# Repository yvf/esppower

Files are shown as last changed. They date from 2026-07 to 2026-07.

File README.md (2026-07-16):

# AC Power Detector & Linear Actuator Driver for HomeKit / Matter

A small battery-powered device that watches for mains AC power and, when the power
drops, extends a  with a linear actuator (meant to physically switch power back on)
and interfaces with Apple Home over Matter/Thread.

It's aimed at unattended installations where a *nuisance* trip would otherwise leave
something important without power until someone visits: an off-grid pump, a remote
freezer, a holiday home. The device notices the outage, attempts a reset, and if the
supply doesn't come back it stops and raises an alert.

## What it does

- **Senses mains power** contactlessly - a custom EMF sensor board picks up the field
  around a live conductor, so there's no direct mains connection to the electronics.
- **Auto-resets on power loss** - after a debounce, it drives the actuator through one or
  two reset cycles. If power returns, it stands down; if not, it latches and waits.
- **Manual reset from your phone** - tap the tile in Apple Home to fire a reset cycle.
- **Live status + trip alerts** - Home shows whether power is present and can notify you
  when it's lost.
- **Battery friendly** - contactless sensing (no mains tap), efficient bare-metal
  firmware, and a low-power Thread mesh radio make long battery operation practical.
- **12v supply** - requires a 12v supply (required for the actuator) and drives 5v from
  there.

## In Apple Home

The device appears as two tiles under one accessory:

- a **contact sensor** (the main tile) - power present / lost, with trip notifications;
- a **switch** - tap to trigger a manual reset (it returns to off on its own).

See [`docs/matter_device_choices.md`](docs/matter_device_choices.md) for why those Matter
device types were chosen.

## Hardware

- **Espressif ESP32-H2** - a RISC-V microcontroller with built-in 802.15.4 (Thread) and
  Bluetooth radios. Development uses the ESP32-H2 devkit.
- **Custom EMF sensor board** - a contactless mains-presence detector with an op-amp front
  end. Design files (schematic, PCB, BOM, gerbers) and write-up are in
  [`emf_sensor/`](emf_sensor/).
- **Actuonix L12 linear actuator** - the small motor that mechanically flips the breaker
  lever, driven as a standard RC servo.

## Software & stack

Bare-metal **`no_std` Rust** (no operating system), talking **Matter over Thread** so the
device joins an existing Apple Home / Thread network. The main building blocks:

- **esp-hal / esp-rtos** - chip support and async runtime
- **OpenThread** - the Thread (802.15.4) mesh networking
- **trouble** - Bluetooth, used only for initial pairing
- **rs-matter** - the Matter application layer

Running bare-metal (rather than on a full RTOS framework) is what makes the whole stack
fit in the ESP32-H2's limited memory - and keeps power draw low. The reasoning, the full
component list, and how to build/flash are in
[**`docs/no-std-plan.md`**](docs/no-std-plan.md).

## Build

```sh
./build.sh                 # build the firmware
./build.sh run --release   # flash to a connected ESP32-H2 and monitor
```

Host prerequisites are listed in [`docs/no-std-plan.md`](docs/no-std-plan.md).

## More documentation

- [`docs/no-std-plan.md`](docs/no-std-plan.md) - architecture, dependency stack, build setup
- [`docs/matter_device_choices.md`](docs/matter_device_choices.md) - the HomeKit / Matter device model
- [`docs/phase4b-glue-design.md`](docs/phase4b-glue-design.md) - the Matter transport layer design
- [`emf_sensor/`](emf_sensor/) - the custom power-sensor board and detection approach

## Status

Working end-to-end on hardware: it commissions over Bluetooth, operates over Thread,
drives the actuator, and reports power status to Home. It currently uses Matter's standard
**test** device credentials - fine with tools like chip-tool and Home Assistant; adding it
to **Apple Home** requires production Matter credentials (a certified vendor ID + device
certificate).

## Disclaimer

More seriously: the code is almost entirely written by Claude, with only high-level human review.
It works for me, compiled on my M2 MacBook, on my esp32-h2 version and other bits. No guarantee it
will for you.

Somewhat less seriously, but perhaps needs saying: this implements a device that affects the real
world. Exercise good judgement, and use at your own risk. Fiddling around with mains AC power and
RCDs is inherently risky. It works for my usecase, but YMMV. If you don't know what you're doing, and
this ends up launching your house all the way to the moon and you with it, don't blame me.

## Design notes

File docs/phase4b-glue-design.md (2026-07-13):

# Phase 4b - rs-matter-stack transport glue (design / roadmap)

> **Status (2026-07-05): fully implemented and working on hardware.** All five
> adapters exist under `src/matter/` (`net.rs`, `netif.rs`, `mdns.rs`, `netctl.rs`,
> `gatt.rs`) and the stack commissions + operates end-to-end. **Key deviation from
> the plan below:** the run loop uses **non-concurrent `stack.run(...)`, NOT
> `run_coex(...)`** - on the H2's single shared radio, BLE + Thread simultaneously is
> unreliable, so BLE runs only while un-commissioned and shuts off once a fabric
> exists (`PreexistingWireless` implements both `Thread`+`Gatt` and `ThreadCoex`, so
> it's the same five adapters, different orchestration). See `src/matter/stack.rs`.
> The C2 variable-length wrinkle (below) was solved with a `heapless 0.9` Vec value.

Goal: run a Matter-over-Thread node by feeding rs-matter-stack our openthread
(Thread) + trouble (BLE) transports. The full dependency graph already builds
(Phase 4a); this is the integration code.

## Approach: `PreexistingWireless` (no custom `ThreadCoex`)

rs-matter-stack provides `PreexistingWireless<S, N, C, M, P>` which **already
implements `Thread` + `ThreadCoex`** (`wireless/thread.rs:478,501`) given five
components. So we don't implement `ThreadCoex` by hand - we supply adapters and
hand the bundle to `ThreadMatterStack::run_coex(...)`:

```
PreexistingWireless::new(net_stack, netif, net_ctl, mdns, gatt)
  S = NetStack                          (UDP over Thread)
  N = NetifDiag + NetChangeNotif        (interface addresses)
  C = NetCtl + ThreadDiag + NetChangeNotif   (apply dataset / status)
  M = Mdns                              (service registration)
  P = GattPeripheral                    (BLE commissioning)
```

The device gets onto Thread **during Matter commissioning**: the commissioner
sends the operational dataset via the NetworkCommissioning cluster -> our `NetCtl`
applies it to openthread (`set_active_dataset_tlv` + `enable_thread`). This is why
we don't need to hardcode `THREAD_DATASET` for the real flow.

## Adapters to write (order = easiest->hardest; build after each)

All rs-matter traits are reachable as `rs_matter_stack::matter::dm::...`. NOTE the
embassy-sync split: trouble pulls 0.7, rs-matter pulls 0.8 - any `Mutex` inside
an adapter that touches rs-matter types must use **0.8** (rs-matter-stack's),
e.g. `rs_matter_stack::matter::utils::sync::...` / `CriticalSectionRawMutex`.

1. **NetStack** (`rs_matter_stack::nal::NetStack`) - `OpenThread` already impls
   edge-nal `UdpBind`/`UdpConnect` (`openthread/src/enal.rs`). Wrap it: `udp_bind`/
   `udp_connect` -> the OpenThread handle; `tcp_bind`/`tcp_connect`/`dns` ->
   `rs_matter_stack::nal::noop::NoopNet` (Matter-over-Thread is UDP-only).
   Watch the GAT lifetimes (`type UdpBind<'a>`).

2. **Netif** = `NetifDiag` + `NetChangeNotif` (`dm::clusters::gen_diag` +
   `dm::networks`). `netifs()` builds a `NetifInfo` from `ot.ipv6_addrs(..)` +
   `ot.net_status()` (interface type = `Thread`); `wait_changed()` =
   `ot.wait_changed().await`.

3. **Mdns** (`rs_matter_stack::mdns::...`/`dm`) - register the Matter operational
   + commissionable services over openthread **SRP** (`ot.srp_set_conf` +
   `ot.srp_add_service`, see `openthread/examples/.../srp.rs`).

4. **NetCtl** + **ThreadDiag** (`dm::clusters::net_comm` + `thread_diag`) - the
   critical one. `NetCtl`: apply the dataset the commissioner provides
   (`ot.set_active_dataset_tlv` + `ot.enable_thread(true)`), report scan/connect.
   `ThreadDiag`: report role/pan-id/channel from `ot.net_status()`/`ot.netdata`.

5. **GattPeripheral** (`rs_matter_stack::ble::GattPeripheral`) - **the hardest;
   not yet implemented.** It owns the whole BLE stack lifecycle (trouble Host +
   runner + GATT server + advertise + the BTP pumps), so it's roughly Phase-3-in-
   full plus the BTP shuttle. All the pieces are researched - concrete build sheet:

   **BTP service** (`#[gatt_service]`, reuse the Phase-3 trouble pattern):
   - Service UUID `0000FFF6-0000-1000-8000-00805F9B34FB` (16-bit 0xFFF6).
   - **C1** `18EE2EF5-263D-4559-959F-4F9C429F9D11` - props `write`
     (commissioner->device). C1_MAX_LEN = `MAX_BTP_SEGMENT_SIZE + GATT_HEADER_SIZE`.
   - **C2** `...9D12` - props `indicate` (device->commissioner) + a CCCD.
   - (C3 `...8F04`, `read`, additional-commissioning-data - optional; skip first.)
   - Constants in `rs_matter::transport::network::btp::gatt` (UUIDs, lengths).

   **`run(&mut self, btp, service_name, service_adv)`:** build the trouble Host
   from the stored `BleConnector`/controller (as Phase-3 `ble_peripheral`);
   advertise the BTP service with `service_adv` (an `AdvData` - encode its bytes
   into the adv payload alongside the 0xFFF6 service UUID); `accept()` ->
   `with_attribute_server`; then `select3` of:
   - **runner** (`runner.run()`),
   - **incoming pump**: on `GattConnectionEvent::Gatt{event}` where
     `WriteEvent::handle() == server.btp.c1.handle` -> `btp.process_incoming(
     Some(conn.raw().att_mtu()), peer_to_btaddr(conn.raw().peer_address()),
     event.data())`; then `event.accept()`.
   - **outgoing pump**: `loop { btp.wait_outgoing().await; let n =
     btp.process_outgoing(Some(mtu), &mut buf)?; if n>0 { server.btp.c2
     .indicate(&conn, &buf_value).await } }`.

   **trouble API confirmed (0.6):** `Characteristic::indicate(&conn, &value)`
   (attribute.rs:970, no-op if CCCD unsubscribed); `WriteEvent::handle()`/`data()`
   (gatt.rs:408+); `Connection::att_mtu()` (connection.rs:486);
   `Connection::peer_address() -> BdAddr` (501) -> map to `rs_matter...btp::BtAddr`.

   **Wrinkle to solve:** trouble characteristics are *typed/fixed-size* but C2
   indications are *variable-length*. First cut: declare C2 as `[u8; C2_MAX_LEN]`
   and indicate the fixed buffer; verify on hardware whether the peer needs the
   exact length (if so, use trouble's variable-length value path). This is the
   main thing to validate with a real commissioner.

   Shape: `run` advertises the BTP service then `select`s the trouble runner, the
   incoming pump (`process_incoming`), and the outgoing pump (`process_outgoing`).

## Run loop (after adapters compile)

`ThreadMatterStack::<BUMP, ()>` in a `StaticCell` (mind RAM - we have lots now);
`stack.run_coex(PreexistingWireless::new(...), &crypto, (NODE, handler), &kv, ())`.
Device model + handler = the On/Off plug (RCD resetter) + the contact sensor
(mains presence). (The shipping firmware uses non-concurrent `run`, not `run_coex`
- see `no-std-plan.md`.)

## Build

`./build.sh` - see `no-std-plan.md` for the host prerequisites (brew-LLVM clang, cmake).

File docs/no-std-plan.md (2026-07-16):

# no-std Matter-over-Thread firmware (ESP32-H2) - architecture & build

## Why no-std (rather than ESP-IDF)

The conventional path for Matter-over-Thread on Espressif is ESP-IDF: the Bluedroid BLE
stack + OpenThread + rs-matter, glued by esp-idf-matter. On the ESP32-H2 that ran into a
hard memory wall - with only **320 KB SRAM**, bringing up Bluedroid + OpenThread +
rs-matter together drove the heap to nearly zero, and the Matter UDP network task failed
to spawn (out of memory). Bluedroid could not be trimmed enough to recover the headroom.

This firmware is bare-metal `no_std` instead. Removing the FreeRTOS/Bluedroid overhead
frees most of the 320 KB for the heap, which is enough to run commissioning and
operation comfortably. (esp-alloc places the heap in the SRAM left over after statics.)

## The stack (all no-std, target `riscv32imac-unknown-none-elf`, nightly)

The firmware is built on **`rs-matter-embassy`** (ivmarkov's off-the-shelf esp
Matter-over-Thread integration), which bundles the whole transport. All the `esp-*` crates
are pinned - via `[patch.crates-io]` in `Cargo.toml` - to a single esp-hal git revision
(`10e48dd...`), the coordinated stack the `rs-matter-embassy` esp example uses;
`openthread` / `openthread-sys` / `mbedtls-rs-sys` track `esp-rs` `main`. See "Why these
exact versions" below.

| Layer | Crate(s) | Notes |
|---|---|---|
| Integration| **rs-matter-embassy** (`esp`,`openthread`,`mbedtls`) | `EmbassyThreadMatterStack` + `EspThreadDriver` = the whole Thread+BLE transport + persistence; we supply only the device model |
| HAL / chip | **esp-hal ~1.1** (`esp32h2`, `unstable`) @ `10e48dd` | peripherals, ADC, LEDC, GPIO |
| RTOS/async | **esp-rtos 0.3** (`esp-radio`,`embassy`) + embassy | scheduler + radio glue |
| Heap | **esp-alloc 0.10** | most of the 320 KB SRAM becomes heap |
| Radio | **esp-radio 0.18** (`ieee802154` + BLE), **stock** @ `10e48dd` | one crate, both radios. The `10e48dd` base has esp-radio 0.18 **with #5650** (the FCF-offset fix); no local patch (see below). |
| Thread | **openthread 0.2** (pinned esp-rs/openthread `main`) | OpenThread C via `openthread-sys`; H2 802.15.4 out of the box; native `UdpSocket` + SRP; edge-nal glue via `edge-nal-openthread`. |
| BLE host | **trouble-host 0.6** on esp-radio's BLE controller | GATT server; version-pinned via rs-matter-embassy (bt-hci 0.8), see below |
| Matter | **rs-matter 0.2** + **rs-matter-stack 0.1** (edge-nal 0.7), both crates.io | generic stack under rs-matter-embassy |
| Boot | esp-bootloader-esp-idf 0.5, esp-backtrace/println | (`esp-bootloader-esp-idf` = the IDF partition-table/app-descriptor format, not the IDF runtime) |

## What we write vs. what rs-matter-embassy provides

`rs-matter-embassy`'s `EmbassyThreadMatterStack` + `EspThreadDriver::new(IEEE802154, BT)`
subsume the entire transport: openthread (Thread netif/UDP/SRP) + esp-radio + trouble (BLE
GATT/BTP) + `edge-nal-openthread` + KV-backed persistence, orchestrated as non-concurrent
BLE-commission-then-Thread. So `src/matter/` is now just the **device model**:

- `stack.rs` - assembles `EmbassyThreadMatterStack`, seeds crypto, builds the node +
  handler chain, wires flash persistence and the factory-reset button, runs the stack.
- `contact.rs` / `plug.rs` - the two endpoint handlers (Contact Sensor + On/Off plug).
- plus `src/{link,controller,sensor,actuator,config}.rs` - the autonomous EMF power-monitor
  / actuator loop, which runs independently of Matter.

The device joins Thread *during* commissioning: rs-matter-embassy applies the operational
dataset the commissioner sends over the NetworkCommissioning cluster. (An earlier version
hand-rolled all of the above transport glue - `NetStack`/`Netif`/`NetCtl`/`Mdns`/
`GattPeripheral` adapters over openthread+trouble - now deleted; `docs/phase4b-glue-design.md`
documents that superseded design.)

## Building (the Makefile)

Build via the **`Makefile`** (it sets up the C-build toolchain env, picks the compile-time
log level, runs preflight checks, and finds the serial port). `build.sh` is the older
wrapper it replaces.

```sh
make                 # cargo build, ESP_LOG=debug   (default target)
make release         # cargo build --release, ESP_LOG=info
make flash           # build debug + flash
make flash-release   # build release + flash
make run             # build debug + flash + monitor (symbolized panics)
make monitor         # attach espmonitor to the device
make clean           # cargo clean + remove esp*.out / chip-tool.out captures
make clean-cache     # drop only the mbedtls/openthread C-build caches (see below)
make help            # list targets + the detected serial port
```

- **Log level** is a *compile-time* constant: the firmware calls
  `esp_println::logger::init_logger_from_env()`, which bakes `ESP_LOG` in at build time, so
  changing it forces a rebuild. Per-target defaults are `debug` for debug builds and `info`
  for release; override on any target with `LOG=trace|debug|info` (e.g.
  `make flash LOG=trace`).
- **Serial port** is auto-detected (`/dev/cu.usbserial-*` / `cu.usbmodem*`) and exported as
  `ESPFLASH_PORT`; override with `PORT=/dev/cu.XXX`.

## Build requirements (host)

**macOS only.** The C-build setup below assumes Homebrew LLVM paths; the Makefile hard-fails
on non-Darwin. Requirements:

- **Rust nightly >= 1.95** (the `10e48dd` esp crates require it). The toolchain is pinned to
  `nightly` with the `riscv32imac-unknown-none-elf` target + `rust-src` via
  `rust-toolchain.toml`; `rustup update nightly` if it's too old.
- **A RISC-V-capable clang** - Apple's `/usr/bin/clang` has **no** riscv32 target, so the
  `mbedtls-rs-sys` / `openthread-sys` C build needs **Homebrew LLVM**: `brew install llvm`.
  The Makefile discovers it with `brew --prefix llvm` (Apple-Silicon and Intel) and puts its
  `bin` on `PATH` + sets `LIBCLANG_PATH` (for bindgen). Override with
  `make <target> LLVM_PREFIX=/path/to/llvm`.
- **cmake** - `brew install cmake`. Any 3.x or **>= 4.4** works. The mbedtls toolchain file
  sets `CMAKE_SYSTEM_NAME=Generic` so cmake must not add the macOS host `-arch` flag (clang
  rejects `-arch` for riscv: `unsupported option '-arch' for target 'riscv32'`). Early cmake
  **4.x (4.0-4.3)** had a regression that leaked `-arch` despite `Generic` (fixed in 4.4);
  the Makefile warns if it sees that range.
- **espflash** / **espmonitor** - `cargo install espflash espmonitor` (needed for `make
  flash` / `run` / `monitor`).

The Makefile's `preflight` target checks the OS, cmake, and LLVM before building and emits an
actionable message (with the `brew`/`cargo install` command) if any is missing.

> `mbedtls-rs-sys` does an **on-the-fly mbedtls C build** (our crypto feature subset differs
> from its committed prebuilt config), and `openthread-sys` links OpenThread; both are why
> clang + cmake are required. A fresh build after a failed one can leave a corrupt mbedtls
> cmake cache (compiler-test / configure failures) - run **`make clean-cache`** (=
> `cargo clean -p mbedtls-rs-sys -p openthread-sys`) then rebuild, rather than a full
> `make clean`.

## Key implementation decisions & constraints

**Commissioning is non-concurrent, not coex.** The H2 has a single 2.4 GHz radio shared
between BLE and 802.15.4; running both simultaneously is unreliable. `rs-matter-embassy`'s
`EmbassyThreadMatterStack::run` is non-concurrent (advertises
`SupportsConcurrentConnection = false`): BLE only while un-commissioned, then Thread-only
once a fabric exists. `EspThreadDriver` implements the driver traits for both modes, so this
is just an orchestration choice, not different code paths.

**Why these exact versions (stock esp-radio, the `10e48dd` base).** We pin all esp crates to
esp-hal git rev `10e48dd` - the last commit where **esp-radio is still 0.18 and already has
#5650** (the FCF AR-bit / frame-version offset fix). This is the base the `rs-matter-embassy`
esp example uses, and on it **stock esp-radio works end-to-end on H2 + Apple** (BLE commission
-> attach as child -> SRP register -> operational CASE over Thread), with no local esp-radio
patch.

**Persistence is handled by rs-matter-embassy.** The Matter fabric, the Thread network, and
the OpenThread SRP key are flash-backed via rs-matter-embassy's `SeqMapKvBlobStore` over the
`nvs` partition (located at runtime from the esp-idf partition table; `src/matter/stack.rs`
`get_persistent_store`, wrapping esp-storage's blocking `FlashStorage` in
`embassy_embedded_hal::adapter::BlockingAsync`). So pairing survives reboots and a
commissioned device comes straight back up over Thread (no BLE). GPIO5 held 3 s triggers a
factory reset (`stack.matter().reset_persist(kv)` then software reset).

**BLE version matrix (don't drift).** openthread pins **esp-radio 0.18 -> bt-hci 0.8.1**, so
BLE uses **trouble-host 0.6** (also bt-hci 0.8.1); trouble `main`/0.7 needs bt-hci 0.9 and
won't typecheck against `BleConnector`. rs-matter-embassy owns the trouble/bt-hci dependency
and the trouble `#[gatt_server]` / `embassy-sync` version juggling internally, so our direct
`embassy-sync` dep is plain **0.8**. esp-radio needs both `ieee802154` and `ble` features.

**Crypto version conflict (resolved).** `ccm 0.4.4` (pulled by `ieee802154 0.6.1` ->
esp-radio's 802.15.4 AES-CCM) pins `subtle "=2.4"` exactly, vs rs-matter's `subtle ^2.6`.
No public `ccm 0.4.x` relaxes that pin (0.5.0+ do - with `subtle = "2"` - but are
semver-incompatible with `ieee802154`'s `^0.4.0`), so `[patch.crates-io] ccm` points at a
one-line branch of the `yvf/AEADs` fork that relaxes it to `subtle = "2"` (the same value
ccm 0.5.0 uses; API-compatible for ccm's constant-time tag compare). A direct
`subtle = "2.6"` dep forces unification to 2.6.1, so `ccm 0.4.4` (esp-radio) and `ccm 0.5`
(rs-matter) coexist on one `subtle`. (Previously this was a `vendor/ccm` path copy; the
fork branch removes the in-repo source tree - the branch is the only change.)

**Crypto RNG seeds from the digital RNG, not the TRNG (ADC1 stays free).** The
rs-matter-embassy esp example seeds its CSPRNG from `TrngSource::new(RNG, ADC1)` - but this
firmware needs **ADC1** for the contactless EMF sensor (GPIO4). So `src/matter/stack.rs`
seeds `default_crypto` from the plain digital `Rng::new()` (a ZST, no ADC1) via a small
rand_core-0.6 shim (`EspRng`), leaving ADC1 for the sensor.

## Device credentials (bring-up)

The firmware uses rs-matter's **TEST** device credentials (VID 0xFFF1). chip-tool and
Home Assistant accept these; **Apple Home requires a real DAC** (it rejects the CHIP test
PAA root), which needs CSA membership + a certified VID. The Active Operational Dataset
(Thread network key) is supplied at build time via env, never committed.

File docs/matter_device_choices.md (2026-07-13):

# Matter Device Choices for RCD Reset Controller

## Hardware Overview

- **Linear actuator**: extends to reset an RCD to "on", then automatically retracts
- **Power sensor**: detects power state (on/off) downstream of the RCD
- **Controller**: ESP with Matter/Thread radio
- **Ecosystem**: Apple HomeKit via Matter over Thread

---

## Matter Node Structure

Single Matter node, two functional endpoints:

| Endpoint | Device Type | Type ID  | Purpose |
|---|---|---|---|
| 0 | Root Node | - | Required, standard |
| 1 | Contact Sensor | `0x0015` | Downstream power state (**primary**)  |
| 2 | On/Off Plug-In Unit | `0x010A` | Actuator control (manual + automatic) |

### Which endpoint is the primary Home tile

The **contact sensor is the primary accessory** - the tile that represents this device
on the main Home view - and the plug is the secondary tile. Power state is the
at-a-glance information the user cares about (is the RCD tripped?); the plug is an
occasional-use control.

Matter has no explicit "primary endpoint" flag for a composed (non-bridge) device like
this. In practice **Apple Home treats the first application endpoint - the lowest
endpoint ID, listed first in the node's `PartsList` - as the primary tile.** So the lever
is simply endpoint ordering: whichever functional endpoint is numbered `1` becomes the
main tile. We therefore assign the contact sensor to endpoint 1 and the plug to
endpoint 2 (they were originally the other way round).

Notes:
- This is a change in device *composition*, so it takes effect on a fresh commissioning
  (re-pair after flashing). Apple's exact primary-selection heuristic is not publicly
  specified, so verify on hardware after re-pairing.
- Endpoint IDs live in `src/matter/`: `CONTACT_ENDPOINT_ID` (`contact.rs`) and
  `PLUG_ENDPOINT_ID` (`stack.rs`), and the `NODE` endpoint order in `stack.rs`.

---

## Endpoint 1 - Contact Sensor (`0x0015`) - primary tile

**Required clusters**: Boolean State (server-side), Identify

**Firmware behavior**:
- `StateValue = true` -> power present -> HomeKit shows "Closed"
- `StateValue = false` -> power absent (RCD tripped) -> HomeKit shows "Open" with alert notification

**HomeKit UI**: read-only contact sensor tile - the **primary** tile for this device (see "Which endpoint is the primary Home tile" above); HomeKit raises a notification automatically when state goes to "Open" (power lost), providing RCD-trip alerting for free

---

## Endpoint 2 - On/Off Plug-In Unit (`0x010A`) - secondary tile

**Required clusters**: On/Off (server-side), Identify

**Firmware behavior**:
- Receiving `On` command (manual or automatic) -> extend actuator -> wait -> retract -> report `Off`
- `Off` commands are ignored (device is always effectively off at rest)
- During any actuator cycle (manual or automatic), set cluster state to `On`; set back to `Off` when cycle completes - keeps HomeKit's view consistent

**HomeKit UI**: tappable switch/outlet tile (secondary); always returns to off after a cycle, naturally communicating the one-shot/momentary nature of the action

**Why not `Generic Switch (0x000F)` with `MomentarySwitch` feature?**
HomeKit treats Generic Switch as an automation trigger only - no direct control tile in the Home app. The plug-in unit gives a tappable tile while the auto-off behavior communicates the momentary semantics.

**Why not `On/Off Light (0x0100)`?**
Lightbulb icon misleads users.

**Why not `On/Off Light Switch (0x0103)`?**
That is a client-side switch controller, not a controllable output.

---

## Automatic Retry Logic

When the power sensor detects loss of power, the firmware automatically triggers an actuator extend/retract cycle (which may or may not restore power). This logic is entirely internal to the firmware - it does not change the Matter device model.

The automatic cycle uses the same code path as a manual `On` command:

```
power sensor -> false (StateValue = false)
  `-> firmware triggers actuator cycle
        `-> set On/Off cluster to On
              `-> wait
                    `-> retract
                          `-> set On/Off cluster to Off
                                `-> re-read power sensor -> update Boolean State cluster
```

**Future extension**: if auto-retry needs to be user-configurable from HomeKit, add a third endpoint (another On/Off Plug-In Unit as an enable/disable toggle). This is additive and does not affect the existing two endpoints.

---

## HomeKit Home App Appearance

Both endpoints appear under a single device card; the contact sensor is the primary
(main) tile and the plug is the secondary tile:

```
[Power Sensor]  (primary)    [RCD Resetter]  (secondary)
  Contact tile                 Plug tile
  Closed = power on            Off (always at rest)
  Open (!) = RCD tripped       Tap -> fires actuator
  Notification on trip         Auto-fires on trip
```

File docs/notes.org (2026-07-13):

* Prompt(s)

** Green field prompt

I need you to code an "RCD Reset Controller" project. It must be a rust-based (no-std) application for an Espressif ESP32-H2 controller, using the Matter (over Thread) ecosystem, with the goal of being compatible with Apple HomeKit (the key compatibility here is via Matter / Thread). The application is a device to detect 220AC power, and engage a linear actuator when the power fails, but must also include a manual trigger via HomeKit, as well as the display of the detected power status via HomeKit. You do not need to work out the physical wiring or power supply aspects of this system at this stage. The main hardware components are the Espressif ESP32-H2 controller, an Actuonix L12 linear actuator (L12-50-210-12-I), and a SCT-013-000 100A/1v CT sensor connected to the Esp32-H2 via an RBDimmer SCT-013 Adapter. You need to assign pins on the ESP32 to connect both the linear actuator control wires, as well as the CT power sensor adapter. The behavior of the linear actuator, including the choice of matter device types are documented in the matter_device_choices.md file in this directory. The manuals / specifications for the three main hardware components are in the docs subdirectory, including the full esp32 technical reference, should you need them. Ask me questions as required. You should first architect the solution, including selection of rust libraries required, then plan the code structure, then consider the tests required, finally coding the main functionality. There should be both functional tests, as well as some integration tests, although the latter need to run on the actual hardware, and may need to be interactive so that the physical environment and behavior can be externally confirmed.

* Power detection

** Potential solutions

The ACS712 original proposed solution won't work for 220 AC. Instead considering either an optocoupler (but needs 220v direct connection), or an EMF-based solution.

*** EMF Solution with BCS547 amplification

*** CT Sensor with conditioning circuit

SCT-013-000 100A/1v sensor with RBDimmer SCT-013 Sensor Adapter. The code needs to sample the ADC over 100 readings and measure the peak-to-peak swing. A swing above the threshold indicates AC current is flowing (mains present); a flat signal indicates no power.

https://www.poweruc.pl/collections/split-core-current-transformers2/products/split-core-current-transformer-sct013-rated-input-5a-100a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

* Actuator

** Device

Actuonix L12 micro linear actuator L12-50-210-12-I

* Matter & QR code

The code genrates on startup (to the esp32 console, when unpaired) an ascii-art (but usable, depending on font) QR code, as well as the component data that goes into it. It also prints the `MT:xxxxx....` string that's the QR code payload. An actual image can be generated by `chip-tool` thus:

```
chip-tool payload generate-qrcode \
  --discriminator 3840 \
  --setup-pin-code 20202021 \
  --vendor-id 0xFFF1 \  # Well known test vendor ID
  --product-id 0x8004 \
  --version 0 \
  --commissioning-mode 0 \
  --rendezvous 2
```

The MT:... string can be generated with something like:

```
chip-tool payload generate-manualcode \
  --discriminator 3131 \
  --setup-pin-code 20201111 \
  --version 0 \
  --commissioning-mode 0
```

Claude decodes the specific QR code string that our code generates to :

Decoded it - here's the full breakdown. I wrote a quick base38 decoder + bit-unpacker matching the Matter spec's onboarding payload format and ran it against your string.

**Base38 payload (after `MT:`):** `-24J042C00KA064IJ3P0WISA0DK5N1K8SQ1RYCU1O0` -> decodes to 25 raw bytes, the first 11 of which hold the fixed fields:

| Field                  | Value                      | Notes                                                                            |
|------------------------+----------------------------+----------------------------------------------------------------------------------|
| Version                | 0                          | Payload schema version                                                           |
| Vendor ID              | 65521 (`0xFFF1`)           | Standard Matter **test/example** vendor ID                                       |
| Product ID             | 32769 (`0x8001`)           | Test product ID                                                                  |
| Custom Flow            | 0                          | Standard commissioning flow, no special vendor steps                             |
| Discovery Capabilities | `0x02` (binary `00000010`) | Bit 1 set -> **BLE** discovery only                                               |
| Discriminator          | 3840 (`0xF00`)             | Used to pick this device out during BLE scanning                                 |
| Setup Passcode         | 20202021                   | The commissioning PIN - this is the well-known Matter reference/example passcode |
| Padding                | 0                          | Pads fixed fields to a byte boundary                                             |

That fixed block uses exactly 88 bits (11 bytes), which matches the spec layout (3+16+16+2+8+12+27+4 = 88 bits).

**Remaining data (14 bytes) - optional TLV extension:**

There's extra data beyond the fixed fields, which the Matter spec allows for optional vendor info encoded as TLV. Decoding it:
- `0x15` -> start of an anonymous TLV Structure
- `0x2C` -> context tag, UTF-8 string (1-byte length)
- tag `0x00` -> this tag number conventionally means **Serial Number** in Matter's optional QR payload data
- length `0x09` (9 bytes)
- data bytes `31 32 33 34 35 36 37 38 39` -> ASCII for **"123456789"**
- `0x18` -> End-of-Container

So the extension is a serial number field containing the string `"123456789"`.

**Summary:** This is a standard Matter **test/reference** QR code - vendor ID `0xFFF1`, discriminator `3840`, and passcode `20202021` are the well-known default values baked into CHIP SDK example apps (like the all-clusters or lighting sample apps), with BLE-only discovery and an attached serial number of `123456789`. It's not a real production device's code - it's the kind of payload you'd see logged when spinning up a Matter example application for testing.

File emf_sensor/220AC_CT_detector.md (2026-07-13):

# AC Mains Power Detection with ESP32

> **⚠️ SUPERSEDED - historical reference only.** The CT-clamp approach below was the
> first option explored, then set aside in favour of a contactless EMF sensor. The
> current, working sensor is the buffered LM358 design in
> **`220AC_EMF_Remote_detector.md`**.

## Overview

This document summarises the approach for detecting AC mains power presence/absence using a non-invasive inductive sensor connected to an ESP32 microcontroller.

---

## Sensing Method: Current Transformer (CT) Sensor

A **non-invasive current transformer (CT) sensor** is the recommended approach. It clamps around a single wire of the mains cable and requires no direct electrical contact, providing full galvanic isolation between mains voltage and the ESP32.

**Key safety points:**
- The CT clamps around **one wire only** (live or neutral, not both together)
- No mains voltage ever reaches the ESP32
- Keep mains wiring and low-voltage circuitry physically separated

---

## Selected Solution: RBDimmer SCT-013 Sensor Adapter

**Supplier:** [rbdimmer.com](https://www.rbdimmer.com/shop/sct-013-sensor-adapter-31)

This is a purpose-built, commercially available signal conditioning board designed specifically to interface SCT-013 current transformers with microcontrollers like the ESP32. It includes a complete signal conditioning circuit with precision voltage divider and filtering, converting the CT's AC output to a microcontroller-friendly **0-3.3V signal** - no additional components or soldering required.

### Wiring

| Adapter Pin | ESP32 Pin |
|---|---|
| GND | GND |
| VCC | 3.3V |
| SIG | GPIO 32, 33, 34, 35, 36, or 39 (ADC1 pins) |

### CT Sensor

Pair the adapter with an **SCT-013-030** (30A, 1V output variant) or **SCT-013-000** (100A, current output variant). The SCT-013-030 is preferred for this use case as its built-in burden resistor produces a clean 0-1V output directly compatible with the adapter.

Connect the CT sensor's 3.5mm jack directly into the adapter's socket.

Selected the SCT013 (100A, 1V) from [yhdc.com](https://www.poweruc.pl/collections/split-core-current-transformers2/products/split-core-current-transformer-sct013-rated-input-5a-100a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)

---

## ESP32 Code - Presence Detection

```cpp
#define CT_PIN 34
#define SAMPLES 100
#define THRESHOLD 10  // ADC counts above noise floor

bool detectACPresence() {
    int minVal = 4095, maxVal = 0;

    for (int i = 0; i < SAMPLES; i++) {
        int val = analogRead(CT_PIN);
        if (val < minVal) minVal = val;
        if (val > maxVal) maxVal = val;
        delayMicroseconds(100);
    }

    int peakToPeak = maxVal - minVal;
    return peakToPeak > THRESHOLD;
}

void setup() {
    Serial.begin(115200);
    analogReadResolution(12);
}

void loop() {
    bool powerPresent = detectACPresence();
    Serial.println(powerPresent ? "AC PRESENT" : "NO AC");
    delay(500);
}
```

The code samples the ADC over 100 readings and measures the peak-to-peak swing. A swing above the threshold indicates AC current is flowing (mains present); a flat signal indicates no power.

---

## Bill of Materials

| Item | Description | Source |
|---|---|---|
| SCT-013 | 100A/1v non-invasive CT clamp sensor | Amazon / AliExpress |
| RBDimmer SCT-013 Adapter | Signal conditioning board | rbdimmer.com |
| ESP32 DevKit | Microcontroller | Any supplier |

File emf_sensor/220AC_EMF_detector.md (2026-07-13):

# Non-Contact 220V AC EMF Presence Detector

> **⚠️ SUPERSEDED - historical reference only.** This BC547-cascade design only worked
> with the antenna and ESP within a few inches of the live cable; its high-impedance
> output could not be run the several feet the installation needs. It was abandoned in
> favour of the buffered LM358 design in **`220AC_EMF_Remote_detector.md`** (the current,
> working sensor).

This document outlines the design, wiring, and embedded Rust integration required to build a contactless 50/60Hz electromagnetic field (EMF) detector using an **ESP32-H2** and **BC547** transistors.

> **Design note (revised):** the cascade output is read as an **analog ADC input**, not a digital pin. The original digital design did not work; see [Why the output is read as analog](#-why-the-output-is-read-as-analog-not-digital) for the bench investigation that led here.

---

## ⚠️ Important Safety Notice
* **Contactless Isolation:** This project does **not** physically connect to dangerous 220V mains voltage wires. The antenna reads the radiating electromagnetic wave through the wire's outer plastic insulation.
* **Safe Handling:** Never strip the insulation off the 220V AC lines. Keep the copper antenna wire completely isolated from exposed copper conductors.

---

## 🛠️ Hardware Requirements
* **Microcontroller:** ESP32-H2 (RISC-V architecture)
* **Transistors:** 3x BC547 NPN Transistors (Labeled **Q1**, **Q2**, and **Q3**)
* **Current-Limiting Resistor:** 1x 10kΩ Resistor
* **Bleeder/Stabilizing Resistor:** 1x 1MΩ to 10MΩ Resistor
* **Antenna:** A 5cm piece of insulated solid-core copper wire wound into a tight spiral.

### BC547 Pin Configuration
Looking directly at the **flat side** of the transistor with the pins pointing downwards:
1. **Pin 1 (Left):** Collector (C)
2. **Pin 2 (Middle):** Base (B)
3. **Pin 3 (Right):** Emitter (E)

---

## 🔌 Circuit Wiring Diagram

The circuit uses three BC547 transistors stacked into a high-gain Darlington-style cascade to amplify weak alternating electric fields.

```text
               ESP32-H2 3.3V
                 │
                 ├───┐├───┐
                 │   │   │
               ┌─┴─┐┌─┴─┐┌─┴─┐
               │ C ││ C ││ C │
  Antenna ───> │ B ││   ││   │
    │          │ Q1││ Q2││ Q3│
   [ ] 1M-10M  │ E ││ E ││ E │
    │          └─┬─┘└─┬─┘└─┬─┘
   GND ──────────┘    │    │
                      ├────┤    ┌───────┐
                      │    └────┤ 10kΩ  ├────> ESP32 GPIO4 (ADC1_CH3)
                      ▼         └───────┘
                    Base Q3
```

### Step-by-Step Connections:
1. **The Cascade:**
   * Connect **Emitter (E) of Q1** to **Base (B) of Q2**.
   * Connect **Emitter (E) of Q2** to **Base (B) of Q3**.
2. **Power & Ground Rails:**
   * Connect the **Collectors (C) of Q1, Q2, and Q3** together, then connect them to the **3.3V** pin on the ESP32-H2.
   * Connect **Emitter (E) of Q3** directly to a **GND** pin on the ESP32-H2.
3. **The Sensor Input (Antenna):**
   * Connect your spiral copper wire antenna directly to the **Base (B) of Q1**.
   * Place your high-value bleeder resistor (**1MΩ to 10MΩ**) between the **Base (B) of Q1 and GND**. *Note: This prevents static charge buildup from keeping the sensor permanently locked on.*
4. **The Output to ESP32-H2:**
   * Connect a wire to the junction where the **Emitter of Q2 meets the Base of Q3** (the output node).
   * Run this wire through a **10kΩ** series resistor into **GPIO4** on your ESP32-H2.
   * GPIO4 is configured as **ADC1 channel 3** (analog input) - *not* a digital input.

---

## 🔬 Why the output is read as analog (not digital)

The first version of this firmware configured GPIO4 as a **digital input** and counted logic-level transitions. On the bench it detected **zero** transitions even with the antenna held on a live cable. A scope investigation (Rigol DS1104Z) explained why, and the firmware was changed to read the node with the **ADC** instead.

### Node names used below

| Node | Physical point |
|---|---|
| `N_ant` | Base of Q1 - antenna + bleeder |
| `N_A` | Q1 emitter = Q2 base |
| `N_out` | Q2 emitter = Q3 base = the 10 kΩ tap -> GPIO4 |

### Findings

* **The output node is clamped to ~ 0.8 V.** `N_out` is also Q3's *base*, and Q3's emitter is at GND, so the base-emitter junction clamps the node to roughly one diode drop (~0.7-0.8 V). It physically cannot reach the ESP32-H2 input-HIGH threshold (V_IH ~ 0.75 x 3.3 V ~ **2.5 V**). A digital read therefore returns a constant LOW -> no transitions, regardless of how good the antenna coupling is.
* **There is, however, a healthy AC signal there.** Measured peak-to-peak 50 Hz swing at `N_out` (AC-coupled, 20 MHz BW limit, AC-Line trigger):

  | Condition | `N_ant` (Vpp) | `N_out` (Vpp) |
  |-----------|---------------|---------------|
  | Field present (antenna on live cable) | ~350 mV | **~750 mV** |
  | Field absent (away from mains)        | -             | **~300 mV** (ambient noise floor) |

  Both swings sit entirely **below** the 0.8 V clamp.

### Conclusion

The analog front end works fine; only the *interface* was wrong. Reading `N_out` with the ADC and detecting the **peak-to-peak swing** captures the 750 mV-vs-300 mV difference cleanly and sidesteps the logic-threshold problem entirely. No hardware change is required.

> The cascade is a chain of emitter-followers (current gain, ~unity voltage gain) and Q3 effectively acts as a clamp on the output node. If you ever want a true logic-level digital output, the last stage would need to be reworked into a **common-emitter** stage (collector resistor to 3.3 V, output taken at the collector) with base biasing - but for this project the ADC approach is simpler and robust.

---

## 🦀 Firmware integration (this project)

GPIO4 is read as **ADC1 channel 3** using the ESP32-H2's one-shot ADC, sampled fast enough to capture the 50 Hz waveform, then reduced to a peak-to-peak swing and thresholded. The detection logic is identical in shape to the CT backend. (This was the early local-sensor concept; the shipped design is the remote front end in [`220AC_EMF_Remote_detector.md`](220AC_EMF_Remote_detector.md).)

* Implementation: [`src/sensor.rs`](../src/sensor.rs)
* Tunable constants: [`src/config.rs`](../src/config.rs)

### Sampling & detection parameters (`config.rs`)

| Constant | Value | Meaning |
|---|---|---|
| `EMF_SAMPLE_COUNT` | `400` | ADC samples per detection window |
| `EMF_SAMPLE_INTERVAL_US` | `100` | spacing -> 400 x 100 us = **40 ms ~ 2 full 50 Hz cycles** |
| `EMF_DETECTION_THRESHOLD` | `550` | peak-to-peak ADC counts above which AC is "present" |

**Threshold derivation.** 12-bit ADC at 12 dB attenuation ~ 0-3.9 V full scale -> ~ 1.05 counts/mV.

* field present : ~750 mV pp ~ **790 counts**
* field absent   : ~300 mV pp ~ **315 counts**
* threshold sits at the midpoint, ~525 mV ~ **550 counts** (~ 235 counts of margin above the noise floor).

### Core logic (abridged)

```rust
// GPIO4 = ADC1 channel 3, 12 dB attenuation.
let adc = AdcDriver::new(peripherals.adc1)?;
let cfg = AdcChannelConfig { attenuation: attenuation::DB_12, ..Default::default() };
let mut channel = AdcChannelDriver::new(adc, peripherals.pins.gpio4, &cfg)?;

// Sample one 40 ms window (~ two 50 Hz cycles).
let mut buf = [0u16; EMF_SAMPLE_COUNT];
for slot in buf.iter_mut() {
    *slot = channel.read_raw()?;
    // 100 us between samples (Timer in async, sleep in the blocking test path)
}

// Peak-to-peak swing -> presence.
let pp = buf.iter().max().unwrap() - buf.iter().min().unwrap();
let present = pp > EMF_DETECTION_THRESHOLD; // 550 counts
```

---

## 🛠️ Calibration and Tuning

Tune `EMF_DETECTION_THRESHOLD` (ADC counts) in `config.rs`:

* **False positives (reads "present" with no field):** ambient mains hum is exceeding the threshold. Raise `EMF_DETECTION_THRESHOLD`, shorten the antenna, or lower the bleeder resistor (e.g. 10 MΩ -> 1 MΩ) to discharge static faster.
* **Misses a real field:** lower `EMF_DETECTION_THRESHOLD`, lengthen the spiral antenna, or coil it around the outside jacket of the 220 V cable.
* **Re-calibrating from scratch:** scope `N_out` (AC-coupled) with the field present and absent, note the two peak-to-peak voltages, convert to ADC counts (~ 1.05 counts/mV at 12 dB), and set the threshold to the midpoint. The `hw_emf` example also logs the measured peak-to-peak each sample, so you can read the live counts over the serial monitor and pick a threshold without the scope.

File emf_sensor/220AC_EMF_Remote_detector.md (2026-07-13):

# 220 V AC Contactless EMF Presence Detector - Remote (LM358) Design

This is the **current, working** mains-presence sensor for the RCD reset controller. It
uses an **LM358** op-amp as a high-gain, band-limited AC amplifier placed **at the
antenna** (the far/measurement end), buffering the signal so it survives a multi-foot
cable run back to the ESP32-H2. The ESP reads it on **GPIO4 / ADC1_CH3** with a
**calibrated** ADC and infers power presence from the peak-to-peak swing of the 50 Hz
field.

------------------------------
## Background - earlier approaches (abandoned)

This is the third iteration of mains sensing for this project:

1. **CT clamp** (`220AC_CT_detector.md`) - an SCT-013 current transformer with the
   RBDimmer adapter. Explored first, then set aside in favour of a fully contactless,
   lower-cost EMF approach.
2. **BC547 transistor cascade** (`220AC_EMF_detector.md`) - a 3-stage emitter-follower
   amplifier with a ~5 cm spiral antenna, read via the ADC. It detected the field fine,
   **but only with the antenna (and the ESP) within a few inches of the live cable.**
   Its output was high-impedance and low-level, so it could not be run more than a few
   inches to the microcontroller without the signal collapsing into noise.

The installation needs the sensor mounted on the mains cable with the ESP32 **several
feet away**. That distance is exactly what killed the cascade design. This **remote**
design fixes it: the LM358 amplifies *and* low-impedance-buffers the signal right at the
antenna, so the amplified output survives a multi-foot shielded-cable run.

> Both earlier documents are retained for history but are **superseded by this one.**

------------------------------
## System Overview
An LM358 op-amp is configured as a high-gain **inverting AC amplifier** with a low-pass
feedback capacitor, placed directly at the measurement point (end of the wire) to
amplify the weak 50/60 Hz electrostatic field before sending a clean, low-impedance
signal over a long shielded cable. The signal is biased to a ~1.65 V "virtual ground" so
the AC wave swings within the ESP32's 3.3 V tolerance.

------------------------------
## Component Checklist

* IC: LM358 Op-Amp
* Resistors:
  * Two 10 kΩ (virtual-ground voltage divider)
  * One 100 kΩ (input resistor - sets gain with the feedback resistor)
  * One 1 MΩ (feedback / gain - gain ~ Rf/100 kΩ = 10; see *Tuning* for the 2.2 MΩ option)
  * One 100 Ω (cable stabilization)
* Capacitors:
  * Two 0.1 uF (104) ceramic (input DC-block + Pin-3 power-noise filter)
  * **One 2.2 nF (222) ceramic (feedback low-pass - band-limits the amp to ~50 Hz)**
* Antenna: 2-to-3 inch solid copper wire loop or coil
* Cable: 3-to-6 foot shielded cable (3 internal strands + outer shield, 22-24 AWG
  stranded recommended for durability)

------------------------------
## LM358 Circuit Schematic (Sensor End)

```
               +3.3V (From ESP32)
                 │
                [10kΩ]
                 │
  Pin 3 (+) ─────┴─────[10kΩ]───── GND
                 │
               [0.1uF]
                 │
                GND

                 ┌──────────[1MΩ feedback]──────────┐
                 │        ┌────[2.2nF]────┐          │
                 │        │               │          │
  Antenna ─[0.1uF]── Pin 2 (-) ───────────┴──────────┤─ Pin 1 (Out) ─[100Ω]─> Signal wire
                 │                                    │
                [100kΩ]                               │
                 │                                    │
                 └────────────────────────────────────┘
```

The **2.2 nF feedback capacitor sits in parallel with the 1 MΩ feedback resistor**
(Pin 1 <-> Pin 2). With the input high-pass (0.1 uF + 100 kΩ ~ 16 Hz) it makes the stage a
band-pass of roughly **16-72 Hz**, centred on 50 Hz, which rejects the HF hash and
interference spikes that otherwise blur the present/absent detection.

------------------------------
## Pin-by-Pin Wiring Guide

### 1. Power & Virtual Ground
* **Pin 8 (VCC):** incoming 3.3 V wire from the ESP32.
* **Pin 4 (GND):** incoming GND wire from the ESP32.
* **Pin 3 (Non-Inverting Input):** middle of the two-10 kΩ divider (one to 3.3 V, one to
  GND -> ~1.65 V). 0.1 uF from Pin 3 to GND filters power noise.

### 2. Input & Feedback Loop
* **Pin 2 (Inverting Input):** the copper antenna through a 0.1 uF DC-blocking cap; a
  100 kΩ resistor between Pin 2 and Pin 3.
* **Feedback loop:** a 1 MΩ resistor **and** a 2.2 nF capacitor, in parallel, between
  Pin 2 and Pin 1.

### 3. Long-Distance Output
* **Pin 1 (Output):** through the 100 Ω stabilization resistor, then onto the long signal
  wire to the ESP32.

------------------------------
## Cable & Microcontroller Connections

| Long Cable Component | Connection at Sensor End (LM358) | Connection at Host End (ESP32)  |
|---|---|---|
| VCC Wire | Pin 8 | 3V3 Pin |
| GND Wire | Pin 4 | GND Pin |
| Signal Wire | Pin 1 (after 100 Ω resistor) | GPIO4 (ADC1_CH3) |
| Outer Cable Shield | Leave Disconnected | GND Pin (drains EMI noise) |

------------------------------
## Firmware Integration (this project)

GPIO4 is read as **ADC1 channel 3** using esp-hal's one-shot ADC with **line-fit efuse
calibration** (`AdcCalLine`). Calibration matters: the ESP32-H2's *uncalibrated* ADC has
a large built-in offset/gain error (it read ~3730 raw for a 1.65 V input, jamming the
operating point against the 4095 ceiling and **clipping** the AC swing). The calibrated
read corrects the offset/gain and returns values **directly in millivolts**, so the
1.65 V bias reads ~1.3 V mid-range with full headroom and the swing is faithful.

* Implementation: [`src/sensor.rs`](../src/sensor.rs)
* Tunable constants: [`src/config.rs`](../src/config.rs)

### Sampling & detection parameters (`config.rs`)

| Constant | Value | Meaning |
|---|---|---|
| `EMF_SAMPLE_COUNT` | `400` | ADC samples per detection window |
| `EMF_SAMPLE_INTERVAL_US` | `100` | spacing -> 400 x 100 us = **40 ms ~ 2 full 50 Hz cycles** |
| `EMF_DETECTION_THRESHOLD` | `95` | **peak-to-peak millivolts** above which AC is "present" |

Because the read is calibrated, samples are already in mV - there is **no count<->mV
conversion**; the threshold is a true peak-to-peak voltage.

### Field-calibrated levels (LM358 + 2.2 nF feedback)

| Condition | Peak-to-peak at GPIO4 |
|---|---|
| Field present | ~200 mV (ranges 150-300 mV) |
| Field absent | mostly < 100 mV (occasional spikes to ~190 mV) |
| DC operating point (mean) | ~1285 mV, stable |

`EMF_DETECTION_THRESHOLD = 95` sits just above the typical absent floor.

------------------------------
## Tuning

* **See the live readings:** build with debug logging - `./build.sh -d run
  --release` - and watch the `EMF sensor: pp = N mV ... mean = N mV` line. `./build.sh -d`
  sets `ESP_LOG=debug` (a compile-time level), so a rebuild is required to change it.
* **Misses a real field / want more amplitude:** increase the feedback resistor 1 MΩ -> 2.2
  MΩ (gain 10 -> 22), keeping a feedback cap (1 nF with 2.2 MΩ ~ 72 Hz). A bigger/closer
  antenna improves signal-to-noise better than raw gain alone.
* **LM358 headroom caveat:** on a 3.3 V supply the LM358 output can only swing up to
  ~1.8 V. With the bias at ~1.3 V there is ~0.5 V of upward room. **Watch the `max` field
  in the debug log - if it approaches ~1800 mV the op-amp is clipping**; lower the Pin-3
  bias (e.g. divider 27 kΩ/10 kΩ -> ~0.9 V) for symmetric headroom, or use a rail-to-rail
  op-amp (MCP6002/TLV9062).
* **False positives from noise:** the absent-state spikes can momentarily cross a low
  peak-to-peak threshold. Raise the threshold, tighten the feedback low-pass (larger
  feedback cap), or switch the firmware metric from peak-to-peak to an RMS / multi-window
  average (more robust to single-sample spikes).

------------------------------
## Key Construction Rules

* **Noise Mitigation:** use a shielded cable (old USB or audio cable) for runs longer than
  3 feet to stop the wire acting as a giant interference antenna. Ground the shield at the
  **ESP end only**.
* **Wire Selection:** 22-24 AWG stranded. The circuit draws under 2 mA, so thickness
  doesn't affect power loss, but stranded wire survives flexing over long runs.
* **Signal Protection:** the 100 Ω resistor at Pin 1 keeps the long cable's capacitance
  from making the op-amp oscillate. The 2.2 nF feedback cap also helps here by rolling off
  HF gain.

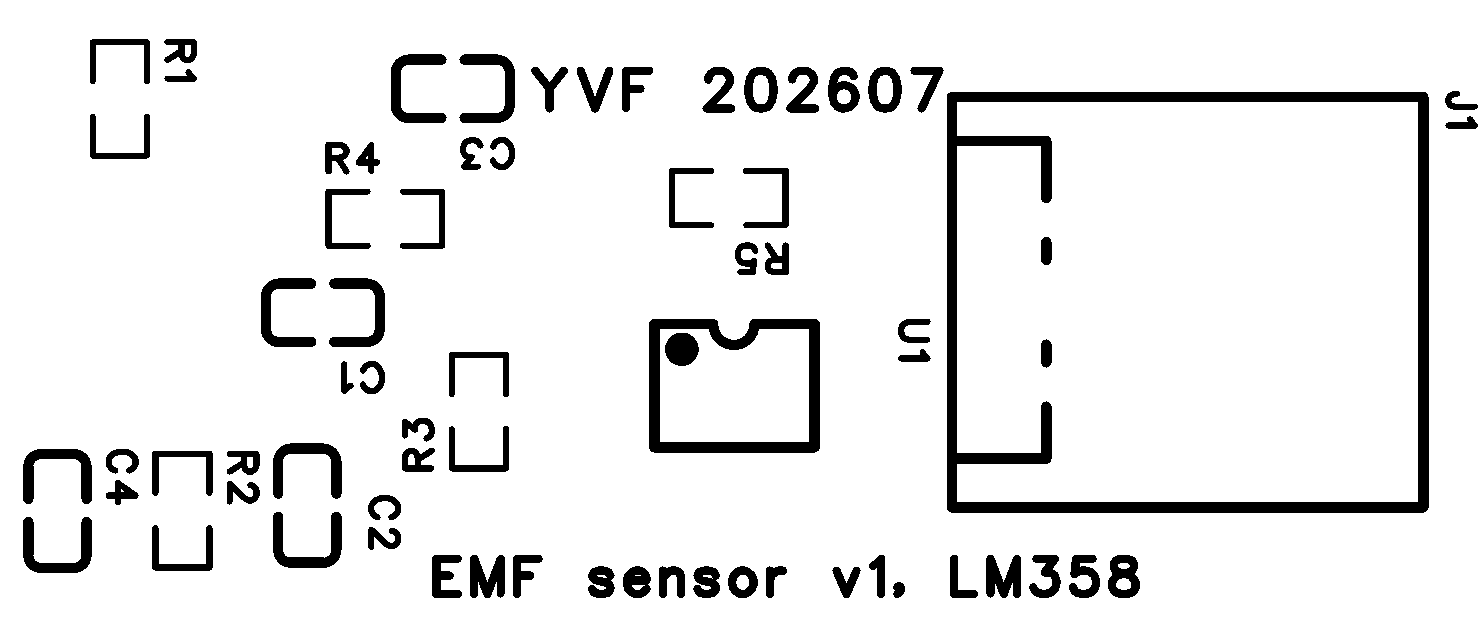
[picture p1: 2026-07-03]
emf_sensor/PCB Production files from factory/12967166a_y2/yg/GBR_11854229_1_top.png

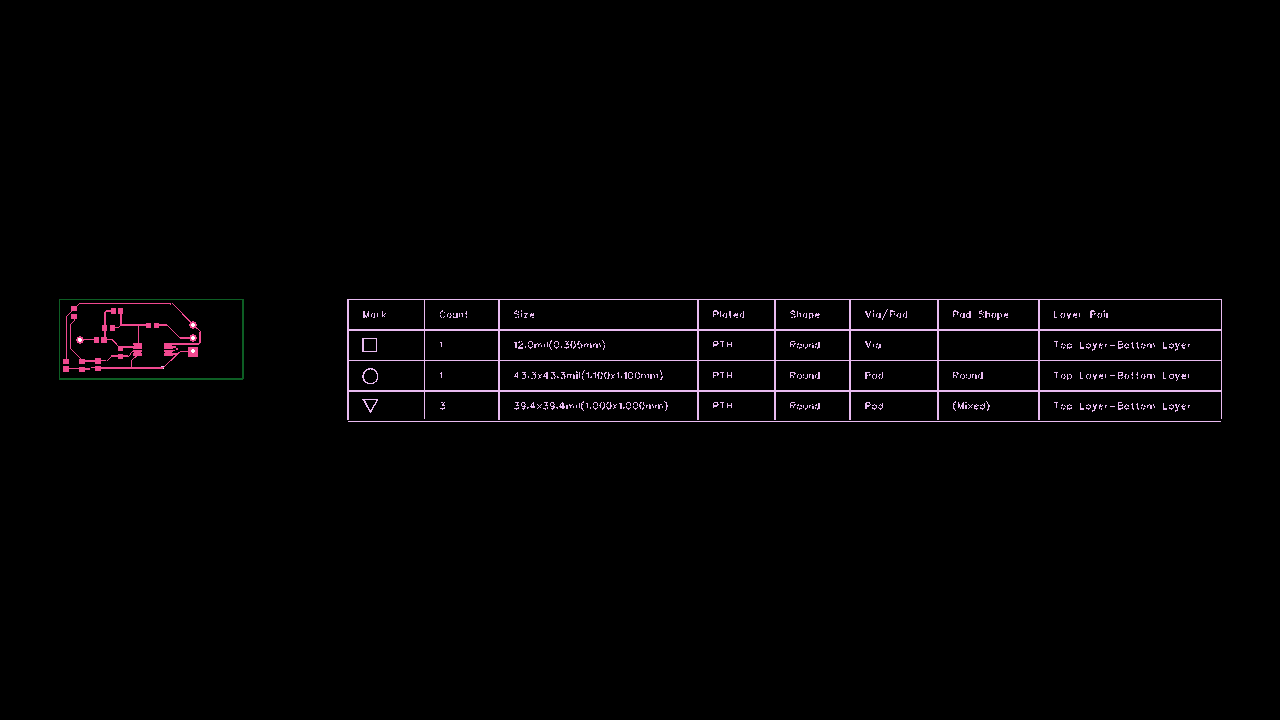
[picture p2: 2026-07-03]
emf_sensor/PCB Production files from factory/12967166a_y2/yg/GBR_11854229_1_snapshot.png

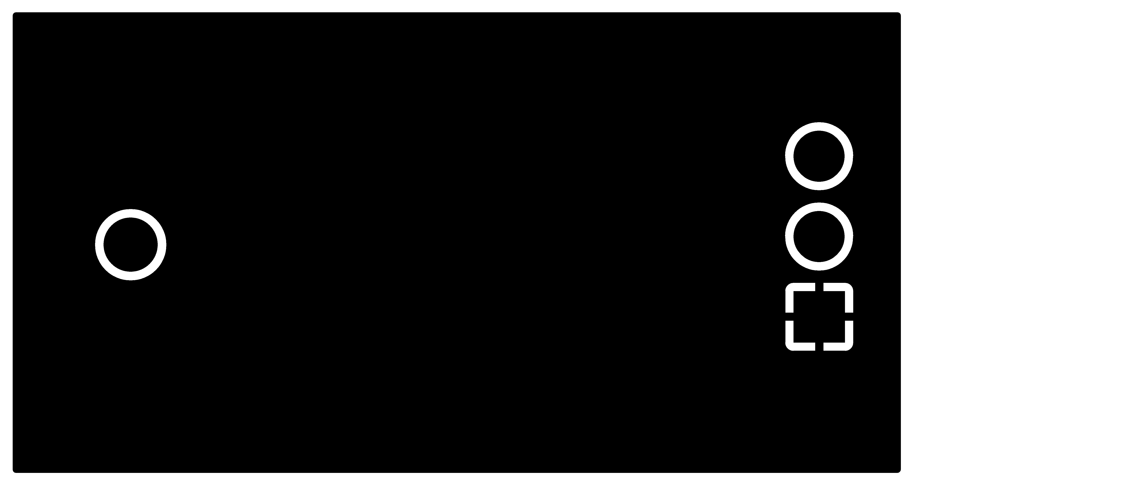
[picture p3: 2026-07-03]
emf_sensor/PCB Production files from factory/12967166a_y2/yg/GBR_11854229_1_bottom.png

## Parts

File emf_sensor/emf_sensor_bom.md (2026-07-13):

# EMF Mains-Presence Sensor - SMD Bill of Materials

Front end for the RCD controller's power sensor (see `220AC_EMF_Remote_detector.md` and
`emf_sensor_schematic.svg`). All parts chosen as **0603 / SOIC** surface-mount so the
board can be machine-assembled. LCSC part numbers are given for **JLCPCB SMT assembly**;
generic MPNs are given so the design ports to any assembler / distributor (Mouser, Digi-Key).

> ⚠️ **Verify the LCSC numbers and stock at order time.** JLCPCB's stock and the
> Basic/Extended classification change frequently; a part marked *Basic* today may be
> *Extended* (small per-part fee) tomorrow. The values, packages and dielectrics below are
> what matters - match those if a specific code is out of stock.

## Components

| Ref | Qty | Value | Package | Notes | MPN | LCSC | JLC type |
|-----|-----|---|---|---|-----|---|---|
| U1 | 1 | LM358 (dual op-amp) | SOIC-8 | One half used; tie off the other (see notes) | LM358DR | C7950 | Basic |
| R1, R2 | 2 | 10 kΩ 1% 1/10 W | 0603 | Virtual-ground divider | 0603WAF1002T5E | C25804 | Basic |
| R3 | 1 | 100 kΩ 1% | 0603 | IN- <-> virtual ground (sets gain) | 0603WAF1003T5E | C25803 | Basic |
| R4 | 1 | 1 MΩ 1% | 0603 | Feedback (gain ~ R4/R3 = 10) | 0603WAF1004T5E | C22935 | Basic |
| R5 | 1 | 100 Ω 1% | 0603 | Output / cable stabilization | 0603WAF1000T5E | C22775 | Basic |
| C1 | 1 | 100 nF 50 V X7R | 0603 | Antenna DC block | CL10B104KB8NNNC | C14663 | Basic |
| C2 | 1 | 100 nF 50 V X7R | 0603 | Virtual-ground bypass | CL10B104KB8NNNC | C14663 | Basic |
| C3 | 1 | 2.2 nF 50 V **C0G/NP0** (X7R ok) | 0603 | Feedback low-pass (~72 Hz band-limit) | CL10C222JB8NNNC | *verify* | Extended (likely) |
| C4 | 1 | 100 nF 50 V X7R | 0603 | VCC decoupling (recommended addition) | CL10B104KB8NNNC | C14663 | Basic |
| J1 | 1 | 4-pin 2.0 mm header, SMD | JST-PH SMD | Cable: 3V3 / GND / SIG / SHLD | S4B-PH-SM4-TB | *verify* | Extended |
| ANT | 1 | Antenna pad | - | Solder a 2-3" copper wire / castellated pad - not a purchased part | - | - | - |

**Consolidated buy:** the three 100 nF (C1, C2, C4) are the same part - order **3x C14663**.

## Assembly / layout notes

1. **Unused op-amp (U1B).** The LM358 is dual; only U1A is used. Tie off the spare to stop
   it oscillating: **pin 5 (+IN) -> GND**, and **short pin 6 (-IN) <-> pin 7 (OUT)**. No extra
   parts - just copper.
2. **C4 decoupling.** Place the 100 nF VCC cap physically close to pin 8 (VCC) <-> pin 4 (GND).
   This was not in the original breadboard design but is standard practice on a PCB.
3. **C3 dielectric.** Prefer **C0G/NP0** for the feedback cap (stable, low distortion); X7R
   works but drifts more with temperature. The exact value isn't critical - 1-2.2 nF sets
   the ~72-160 Hz low-pass corner.
4. **Shield.** J1-SHLD is a pad with **no trace** on this board - the cable shield is grounded
   at the **ESP end only** (per the design doc) to avoid a ground loop.
5. **Antenna.** Keep the ANT pad and the U1 input (pin 2) traces short; that node is high-
   impedance and picks up noise. A short ground pour gap around it helps.

## Optional substitutions

* **Rail-to-rail op-amp** (more output headroom on 3.3 V than the LM358): **MCP6002-I/SN**
  (SOIC-8, LCSC **C7384** - *verify*). Pin-compatible; lets the 1.65 V bias swing further
  before clipping. Only needed if you raise the gain (R4 -> 2.2 MΩ).
* **0402 passives** instead of 0603 if board space is tight - same values, change the
  package and pick the matching LCSC code.
* **Through-hole J1** (cheaper, hand-solderable): a 1x4 2.54 mm header, e.g. LCSC **C2337**.

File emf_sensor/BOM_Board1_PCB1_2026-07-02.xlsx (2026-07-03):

No. | Quantity | Comment | Designator | Footprint | Value | Manufacturer Part | Manufacturer | Supplier Part | Supplier
1 | 3 | CAPR500-350X720X850100nF100V | C1,C2,C4 | C0603 |  | CAPR500-350X720X850100nF100V |  | C2927433 | LCSC
2 | 1 | 2.2nF | C3 | C0603 | 2.2nF | HHV0603R7222K101NTHJ | Chinocera(华瓷) | C5186704 | LCSC
3 | 1 | S3B-XH-A(LF)(SN) | J1 | CONN-TH_S3B-XH-A-LF-SN |  | S3B-XH-A(LF)(SN) | JST | C157928 | LCSC
4 | 2 | 10kΩ | R1,R2 | R0603 | 10kΩ | RC0603FR-0710KL | YAGEO(国巨) | C98220 | LCSC
5 | 1 | 100kΩ | R3 | R0603 | 100kΩ | 0603WAF1003T5E | UNI-ROYAL(厚声) | C25803 | LCSC
6 | 1 | 1MΩ | R4 | R0603 | 1MΩ | 0603WAF1004T5E | UNI-ROYAL(厚声) | C22935 | LCSC
7 | 1 | 100Ω | R5 | R0603 | 100Ω | 0603WAF1000T5E | UNI-ROYAL(厚声) | C22775 | LCSC
8 | 1 | LM358PW | U1 | TSSOP-8_L4.4-W3.0-P0.65-LS6.4-BL |  | LM358PW | TI(德州仪器) | C1347323 | LCSC

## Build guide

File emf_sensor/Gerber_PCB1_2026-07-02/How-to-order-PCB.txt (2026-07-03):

How to Order PCB

Please refer to:
https://prodocs.easyeda.com/en/pcb/order-order-pcb/index.html

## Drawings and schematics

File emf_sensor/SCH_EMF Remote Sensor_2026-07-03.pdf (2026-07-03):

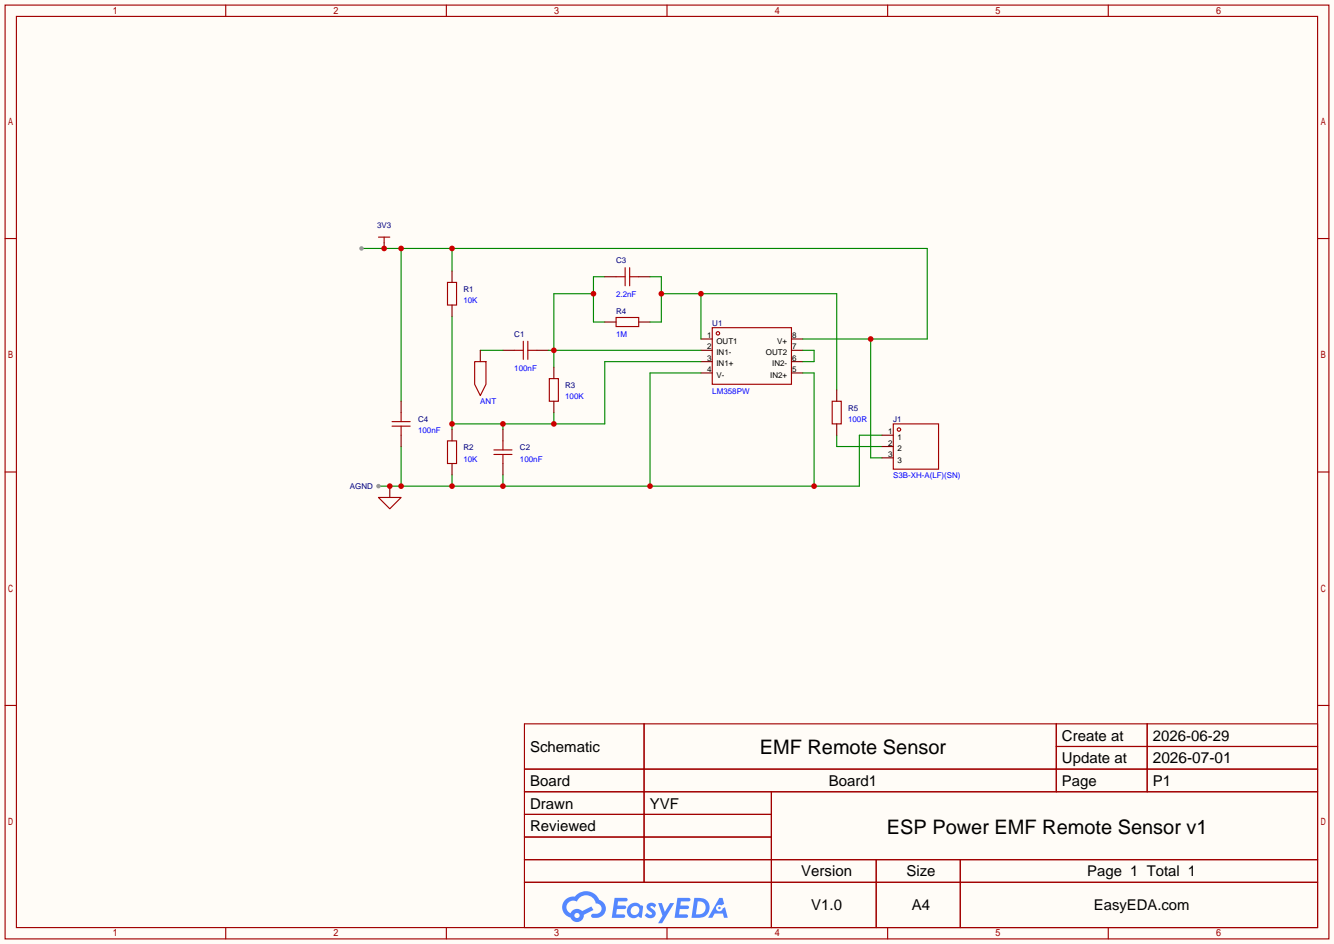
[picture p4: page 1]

Schematic | EMF Remote Sensor | Create at | 2026-06-29

Update at | 2026-07-01

Board | Board1 | Page | P1
Drawn | YVF | ESP Power EMF Remote Sensor v1
Reviewed

Version | Size | Page 1 Total 1
V1.0 | A4 | EasyEDA.com

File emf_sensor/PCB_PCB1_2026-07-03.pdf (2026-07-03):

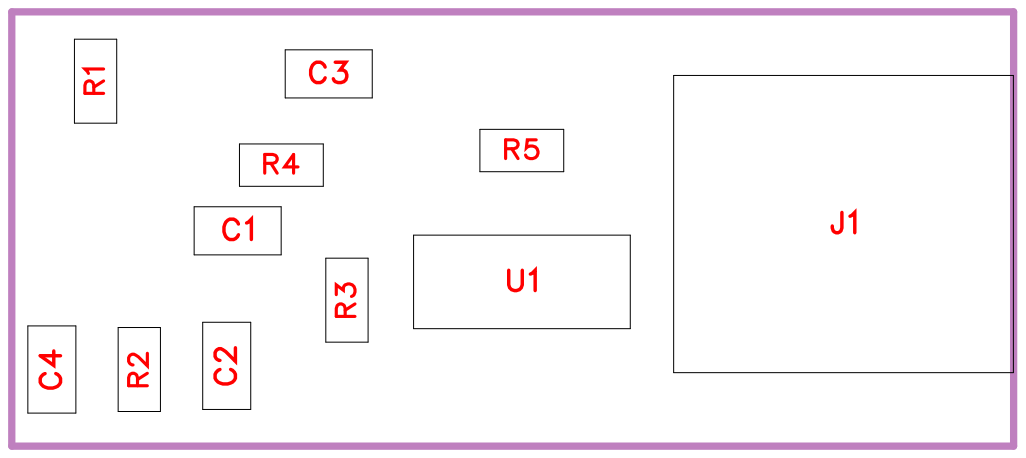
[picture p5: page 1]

No. | Quantity | Comment | Designator | Footprint | Value | Manufacturer Part | Manufacturer | Supplier Part | Supplier
1 | 3 | CAPR500-35 0X720X8501 00nF100V | C1,C2,C4 | C0603 | | CAPR500-35 0X720X8501 00nF100V | | C2927433 | LCSC
2 | 1 | 2.2nF | C3 | C0603 | 2.2nF | HHV0603R7 222K101NTH J | Chinocera( 华 ) 瓷 | C5186704 | LCSC
3 | 1 | S3B-XH-A(L F)(SN) | J1 | CONN-TH_S 3B-XH-A-LF-SN | | S3B-XH-A(L F)(SN) | JST | C157928 | LCSC
4 | 2 | 10k | R1,R2 | R0603 | 10k | RC0603FR-0 710KL | YAGEO(国巨 ) | C98220 | LCSC
5 | 1 | 100k | R3 | R0603 | 100k | 0603WAF10 03T5E | UNI-ROYAL( 厚声 ) | C25803 | LCSC
6 | 1 | 1M | R4 | R0603 | 1M | 0603WAF10 04T5E | UNI-ROYAL( 厚声 ) | C22935 | LCSC
7 | 1 | 100 | R5 | R0603 | 100 | 0603WAF10 00T5E | UNI-ROYAL( 厚声 ) | C22775 | LCSC
8 | 1 | LM358PW | U1 | TSSOP-8_L4 .4-W3.0-P0.6 5-LS6.4-BL | | LM358PW | TI(德州仪器 ) | C1347323 | LCSC

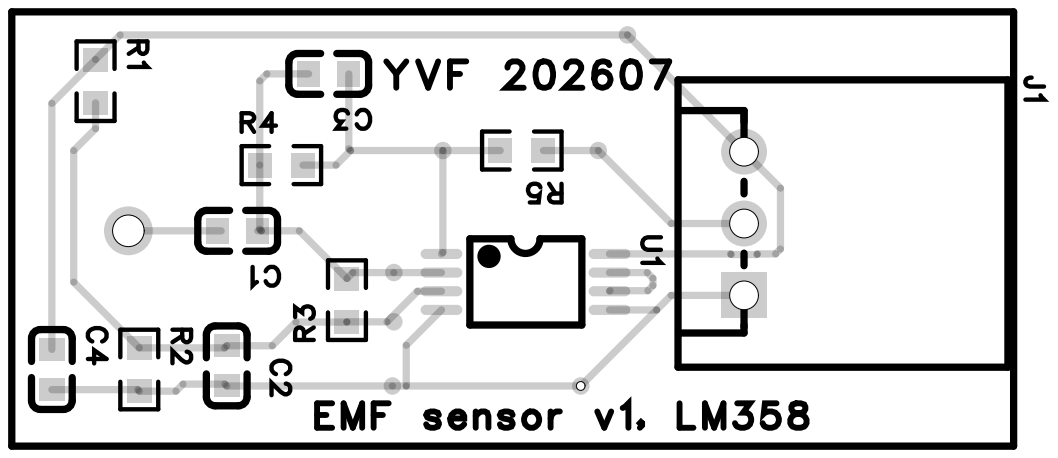
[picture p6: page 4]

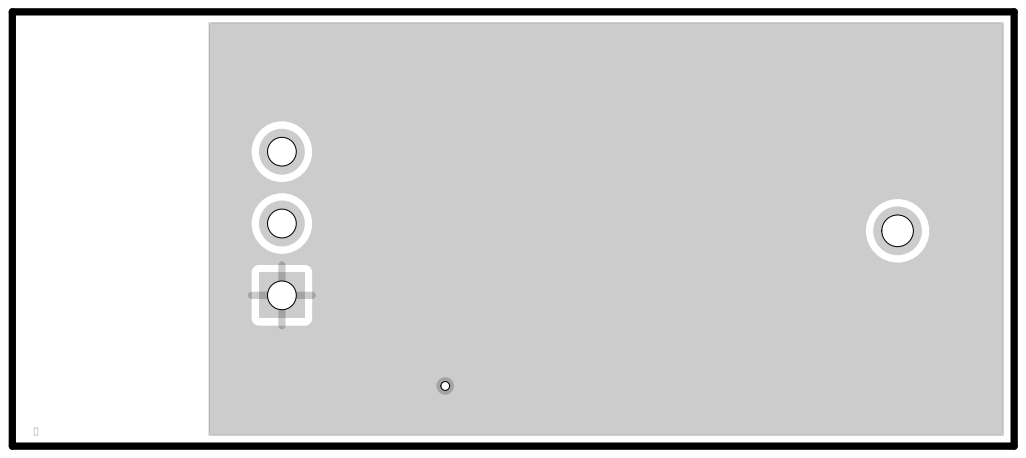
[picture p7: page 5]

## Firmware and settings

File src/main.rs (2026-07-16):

//! RCD Reset Controller - no-std (esp-hal) firmware, ESP32-H2.
//!
//! Matter-over-Thread via `rs-matter-embassy` (BLE commission, then Thread operate,
//! non-concurrent) plus an autonomous EMF power-monitor / actuator auto-reset loop that
//! runs independently of Matter. See docs/no-std-plan.md.

#![no_std]
#![no_main]
#![recursion_limit = "256"]

use embassy_executor::Spawner;
use log::{error, info};

use esp_alloc::heap_allocator;
use esp_hal::ram;
use esp_hal::timer::timg::TimerGroup;
use esp_metadata_generated::memory_range;

use esp_backtrace as _;
use esp_println as _;
use tinyrlibc as _;

mod actuator; // L12 linear actuator over LEDC (GPIO10)
mod config; // power-monitor / actuator timing constants
mod controller; // EMF power monitor + auto-reset state machine
mod link; // shared state between the controller and the Matter device-model handlers
mod matter; // Matter-over-Thread stack (rs-matter-embassy) + our 2-endpoint device model
mod sensor; // contactless EMF power-presence sensor over ADC1 (GPIO4)

esp_bootloader_esp_idf::esp_app_desc!();

/// Timestamp hook for esp-println's `timestamp` feature: every log line (ours and the
/// openthread/rs-matter/esp-radio logs) is prefixed with the uptime in milliseconds, so the
/// reboot-to-operational timeline is measurable. Uses the systimer (works from early boot).
#[no_mangle]
extern "Rust" fn _esp_println_timestamp() -> u64 {
    esp_hal::time::Instant::now()
        .duration_since_epoch()
        .as_millis()
}

/// Heap for the Matter stack + the one alloc-hungry dependency (x509). The reclaimable
/// second RAM region is added as a separate heap so it is not wasted.
const HEAP_SIZE: usize = 100 * 1024;
const RECLAIMED_RAM: usize =
    memory_range!("DRAM2_UNINIT").end - memory_range!("DRAM2_UNINIT").start;

#[esp_rtos::main]
async fn main(spawner: Spawner) {
    esp_println::logger::init_logger_from_env();
    heap_allocator!(size: HEAP_SIZE - RECLAIMED_RAM);
    heap_allocator!(#[ram(reclaimed)] size: RECLAIMED_RAM);
    info!("RCD no-std (Matter over Thread, rs-matter-embassy) starting...");

    let peripherals = esp_hal::init(esp_hal::Config::default());

    let timg0 = TimerGroup::new(peripherals.TIMG0);
    esp_rtos::start(
        timg0.timer0,
        esp_hal::interrupt::software::SoftwareInterruptControl::new(peripherals.SW_INTERRUPT)
            .software_interrupt0,
    );

    // Stable device identity from the chip's factory MAC. This MUST be constant across
    // reboots - it derives the Thread extended (MAC) address, the SRP hostname, and the
    // BLE address. A random EUI-64 each boot makes the device look brand-new to the mesh
    // and the SRP server every time. Expand the 6-byte EUI-48 to EUI-64 (insert 0xFF 0xFE).
    let mac = esp_hal::efuse::base_mac_address();
    let mac = mac.as_bytes();
    let ieee_eui64 = [mac[0], mac[1], mac[2], 0xFF, 0xFE, mac[3], mac[4], mac[5]];
    info!("Device EUI-64 (stable): {ieee_eui64:02x?}");

    // Power monitor + auto-reset. Runs independently of Matter/Thread: the safety function
    // must work whether or not the device is commissioned. Monitors the EMF sensor
    // (GPIO4/ADC1) and drives the L12 actuator (GPIO10/LEDC) on power loss. ADC1 is free
    // for the sensor because crypto seeds from the digital RNG (see matter::stack).
    spawner.spawn(
        run_controller(
            peripherals.ADC1,
            peripherals.GPIO4,
            peripherals.LEDC,
            peripherals.GPIO10,
        )
        .unwrap(),
    );

    // Matter over Thread (commission over BLE, operate over Thread) + GPIO5 factory reset.
    // Never returns (reboots on factory reset or an unexpected stack exit).
    info!("Starting Matter (commission over BLE, operate over Thread)...");
    matter::run_matter(
        peripherals.IEEE802154,
        peripherals.BT,
        peripherals.FLASH,
        peripherals.GPIO5,
        ieee_eui64,
    )
    .await
}

#[embassy_executor::task]
async fn run_controller(
    adc1: esp_hal::peripherals::ADC1<'static>,
    emf_pin: esp_hal::peripherals::GPIO4<'static>,
    ledc: esp_hal::peripherals::LEDC<'static>,
    actuator_pin: esp_hal::peripherals::GPIO10<'static>,
) -> ! {
    let sensor = sensor::EmfSensor::new(adc1, emf_pin);
    let actuator = match actuator::Actuator::new(ledc, actuator_pin) {
        Ok(a) => a,
        Err(e) => {
            error!("Controller: actuator init failed: {e:?} - power monitor disabled");
            core::future::pending().await
        }
    };
    let mut controller = controller::Controller::new(actuator, sensor);
    controller.run().await
}

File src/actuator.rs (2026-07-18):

//! Driver for the Actuonix L12-50-210-12-I linear actuator (esp-hal LEDC backend).
//!
//! Control interface: RC servo (standard hobby protocol).
//! - 50 Hz PWM carrier (20 ms period)
//! - 1 ms pulse (5 % duty)  -> fully retracted
//! - 2 ms pulse (10 % duty) -> fully extended
//! - Signal: 5 V CMOS via an external 3.3->5 V level shifter on GPIO10
//!
//! The `-I` integrated controller auto-detects RC-servo mode on power-up when it
//! sees a valid pulse on lead 4 (White wire).
//!
//! Duty updates go through `Channel::configure` rather than `Channel::set_duty`. On
//! the ESP32-H2 LEDC a duty change is applied via the "gamma" range RAM, and
//! esp-hal 1.1's bare `set_duty` does not reset the gamma write-pointer, so only the
//! *first* duty after channel setup reaches the output (the actuator buzzes once at
//! boot, then never moves). `configure` runs the full channel setup - including the
//! write-pointer reset - every time, so re-running it per duty change reliably
//! re-applies the new pulse width.

use embassy_time::{Duration, Timer};
use esp_hal::clock;
use esp_hal::gpio::DriveMode;
use esp_hal::ledc::channel::{self, ChannelIFace};
use esp_hal::ledc::timer::{self, LSClockSource, TimerIFace};
use esp_hal::ledc::{LSGlobalClkSource, Ledc, LowSpeed};
use esp_hal::peripherals::{GPIO10, LEDC};
use esp_hal::time::Rate;
use log::{info, warn};
use static_cell::StaticCell;

use crate::config::{
    ACTUATOR_EXTEND_DURATION_MS, ACTUATOR_RETRACT_DURATION_MS, SERVO_DUTY_EXTENDED_PCT,
    SERVO_DUTY_RETRACTED_PCT, SERVO_FREQ_HZ,
};

// The `Ledc` and `Timer` must outlive the `Channel` (which borrows the timer) and
// must keep running for as long as PWM is needed. Leaking them to `'static` via
// these cells avoids a self-referential struct and guarantees the timer counter is
// never dropped - dropping it would halt the counter and stop all PWM output, so
// the actuator would stop seeing valid RC pulses and drift to an undefined position.
static LEDC_CELL: StaticCell<Ledc<'static>> = StaticCell::new();
static TIMER_CELL: StaticCell<timer::Timer<'static, LowSpeed>> = StaticCell::new();

// On ESP32-H2, `set_global_slow_clock(APBClk)` selects `ledc_sclk_sel = 0`, which is
// actually the **32 MHz XTAL** (the H2 LEDC has no real APB source). But esp-hal (still
// at rev 10e48dd) computes the timer divisor from `apb_clk_frequency()`, which reports
// 96 MHz on the H2's only clock preset - so the achieved frequency comes out as
// `requested * 32 MHz / 96 MHz`, ~1/3 of the requested rate. That pushes every servo
// pulse past 2 ms and the actuator pins fully extended regardless of duty. We pre-scale
// the requested frequency by `cpu_clock / xtal_clock` (96/32 = 3; CPU == reported APB
// since all H2 preset divisors are 0) so the *achieved* frequency is the true 50 Hz.
// Remove this once esp-hal's `ls_freq_hw` reports the real H2 LowSpeed source clock.

pub struct Actuator {
    channel: channel::Channel<'static, LowSpeed>,
    timer: &'static timer::Timer<'static, LowSpeed>,
}

impl Actuator {
    /// Initialise the LEDC peripheral for RC-servo output on GPIO10 and park the
    /// actuator in the retracted position.
    ///
    /// Returns an error only if the LEDC timer/channel configuration is rejected
    /// (e.g. an unattainable frequency/resolution combination - not expected here).
    pub fn new(ledc: LEDC<'static>, pin: GPIO10<'static>) -> Result<Self, channel::Error> {
        let ledc = LEDC_CELL.init(Ledc::new(ledc));
        ledc.set_global_slow_clock(LSGlobalClkSource::APBClk);

        // Compensate for esp-hal's H2 LEDC clock mislabelling (see module comment above):
        // ask for a scaled-up frequency so the achieved rate is the real 50 Hz.
        let cpu_hz = clock::cpu_clock().as_hz();
        let xtal_hz = clock::xtal_clock().as_hz();
        let requested_hz = ((SERVO_FREQ_HZ as u64 * cpu_hz as u64) / xtal_hz as u64) as u32;
        info!(
            "Actuator: cpu_clock={} Hz xtal_clock={} Hz -> requesting LEDC {} Hz to achieve {} Hz",
            cpu_hz, xtal_hz, requested_hz, SERVO_FREQ_HZ
        );

        let timer = TIMER_CELL.init(ledc.timer::<LowSpeed>(timer::Number::Timer0));
        timer
            .configure(timer::config::Config {
                duty: timer::config::Duty::Duty14Bit,
                clock_source: LSClockSource::APBClk,
                frequency: Rate::from_hz(requested_hz),
            })
            .map_err(|_| channel::Error::Timer)?;
        let timer: &'static timer::Timer<'static, LowSpeed> = timer;

        let channel = ledc.channel::<LowSpeed>(channel::Number::Channel0, pin);
        let mut actuator = Self { channel, timer };
        // Apply the initial (retracted) pulse via the same path used for every later
        // duty change.
        actuator.apply_duty(SERVO_DUTY_RETRACTED_PCT)?;
        info!(
            "Actuator: LEDC ready on GPIO10 @ {} Hz (retracted={}% extended={}%)",
            SERVO_FREQ_HZ, SERVO_DUTY_RETRACTED_PCT, SERVO_DUTY_EXTENDED_PCT
        );

        Ok(actuator)
    }

    /// (Re)configure the channel at the given duty %, which on the H2 is what reliably
    /// pushes a new pulse width to the output. Returns the LEDC error if rejected.
    fn apply_duty(&mut self, duty_pct: u8) -> Result<(), channel::Error> {
        self.channel.configure(channel::config::Config {
            timer: self.timer,
            duty_pct,
            drive_mode: DriveMode::PushPull,
        })
    }

    /// Set the duty %, logging (but not propagating) any LEDC error so a transient
    /// failure can't abort an in-progress reset cycle.
    fn set_duty(&mut self, duty_pct: u8) {
        if let Err(e) = self.apply_duty(duty_pct) {
            warn!("Actuator: set_duty({duty_pct}%) failed: {e:?}");
        }
    }

    /// Drive to the fully-extended position and hold until the stroke completes.
    pub async fn extend(&mut self) {
        info!("Actuator: extending");
        self.set_duty(SERVO_DUTY_EXTENDED_PCT);
        Timer::after(Duration::from_millis(ACTUATOR_EXTEND_DURATION_MS)).await;
    }

    /// Drive to the fully-retracted position and hold until the stroke completes.
    pub async fn retract(&mut self) {
        info!("Actuator: retracting");
        self.set_duty(SERVO_DUTY_RETRACTED_PCT);
        Timer::after(Duration::from_millis(ACTUATOR_RETRACT_DURATION_MS)).await;
    }

    /// Park retracted (resting position between cycles).
    pub fn idle(&mut self) {
        info!("Actuator: idle");
        self.set_duty(SERVO_DUTY_RETRACTED_PCT);
    }
}

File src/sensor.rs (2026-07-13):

//! Contactless EMF power-presence sensor (esp-hal ADC backend).
//!
//! Hardware: an LM358 op-amp configured as a high-gain, band-limited inverting AC
//! amplifier, mounted at the antenna and biased to a ~1.65 V virtual ground. Its
//! low-impedance output is buffered over a multi-foot shielded cable into GPIO4. A
//! 2.2 nF feedback cap band-limits the stage to ~50 Hz. See `220AC_EMF_Remote_detector.md`.
//!
//! GPIO4 is read as a **calibrated analog ADC1 input** (channel 3). Calibration
//! (`AdcCalLine`) corrects the H2's large raw ADC offset/gain error and returns
//! **millivolts**, so the bias sits mid-range with full headroom instead of clipping
//! against the ADC ceiling. Power presence is inferred from the **peak-to-peak swing**
//! of the 50 Hz signal over a sampling window (~200 mV pp live, < 100 mV ambient).

use embassy_time::{Duration, Timer};
use esp_hal::analog::adc::{Adc, AdcCalLine, AdcConfig, AdcPin, Attenuation};
use esp_hal::peripherals::{ADC1, GPIO4};
use esp_hal::Blocking;
use log::debug;

use crate::config::{EMF_DETECTION_THRESHOLD, EMF_SAMPLE_COUNT, EMF_SAMPLE_INTERVAL_US};

/// Detected state of the monitored mains circuit.
#[derive(Debug, Clone, Copy, PartialEq, Eq)]
pub enum PowerState {
    Present,
    Absent,
}

impl PowerState {
    pub fn is_present(self) -> bool {
        matches!(self, PowerState::Present)
    }
}

/// GPIO4 / ADC1_CH3 with line-fit (efuse) calibration. The calibrated read returns
/// **millivolts**, not raw counts - see [`EmfSensor::new`].
type EmfAdcPin = AdcPin<GPIO4<'static>, ADC1<'static>, AdcCalLine<ADC1<'static>>>;

/// ADC-backed EMF detector. Reads the LM358 amplifier output (GPIO4 / ADC1_CH3) as an
/// analog signal and infers AC presence from the peak-to-peak swing.
pub struct EmfSensor {
    adc: Adc<'static, ADC1<'static>, Blocking>,
    pin: EmfAdcPin,
}

impl EmfSensor {
    /// Configure GPIO4 as a **calibrated** ADC1 input.
    ///
    /// 11 dB attenuation (~ 0-3.3 V range). We use `enable_pin_with_cal` with the
    /// line-fit (`AdcCalLine`) scheme rather than a raw `enable_pin`: the ESP32-H2's
    /// uncalibrated ADC has a large built-in offset/gain error (it read ~3730 for a
    /// 1.65 V input, jamming the operating point against the 4095 ceiling and clipping
    /// the AC swing). Calibration applies the efuse offset/gain correction and makes
    /// `read_oneshot` return **millivolts**, so a 1.65 V bias reads ~1650 mV mid-range
    /// with full headroom for the 50 Hz swing both ways.
    pub fn new(adc1: ADC1<'static>, gpio4: GPIO4<'static>) -> Self {
        let mut config = AdcConfig::new();
        let pin = config.enable_pin_with_cal::<GPIO4<'static>, AdcCalLine<ADC1<'static>>>(
            gpio4,
            Attenuation::_11dB,
        );
        let adc = Adc::new(adc1, config);
        Self { adc, pin }
    }

    /// Take one detection window of samples and classify power presence.
    pub async fn sample(&mut self) -> PowerState {
        let mut buf = [0u16; EMF_SAMPLE_COUNT];
        for slot in buf.iter_mut() {
            // The one-shot conversion finishes in a few us; `nb::block!` busy-waits
            // only for that, then we yield for the inter-sample spacing. The read is
            // infallible in practice (error type is `()`); treat a spurious error as 0.
            *slot = nb::block!(self.adc.read_oneshot(&mut self.pin)).unwrap_or(0);
            Timer::after(Duration::from_micros(EMF_SAMPLE_INTERVAL_US)).await;
        }
        let pp = peak_to_peak(&buf);
        let state = detect_power_from_samples(&buf, EMF_DETECTION_THRESHOLD);
        let min = buf.iter().copied().min().unwrap_or(0);
        let max = buf.iter().copied().max().unwrap_or(0);
        let mean = (buf.iter().map(|&s| s as u32).sum::<u32>() / buf.len() as u32) as u16;
        // All values are in millivolts (calibrated read).
        debug!(
            "EMF sensor: pp = {} mV (threshold {} mV), min = {} mV, max = {} mV, mean = {} mV, state = {:?}",
            pp, EMF_DETECTION_THRESHOLD, min, max, mean, state
        );
        state
    }
}

// --- Pure detection logic - no HAL deps --------------------------------------

/// Returns the peak-to-peak swing (max - min) of `samples`.
pub fn peak_to_peak(samples: &[u16]) -> u16 {
    let max = samples.iter().copied().max().unwrap_or(0);
    let min = samples.iter().copied().min().unwrap_or(0);
    max.saturating_sub(min)
}

/// `Present` when the peak-to-peak swing exceeds `threshold`, else `Absent`.
pub fn detect_power_from_samples(samples: &[u16], threshold: u16) -> PowerState {
    if peak_to_peak(samples) > threshold {
        PowerState::Present
    } else {
        PowerState::Absent
    }
}

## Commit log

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2026-06-22 Checkpoint: working RCD controller firmware before Matter pivot
    Tracks the rcd-reset-controller Rust project for the first time, capturing
    the known-good state prior to the esp-idf-matter integration:
    - ESP32-H2 build working (esp-idf-hal 0.46 / embassy 0.10 / esp-idf-svc 0.52)
    - EMF sensor reworked from digital-transition counting to ADC peak-to-peak
    detection on GPIO4/ADC1_CH3 (cascade output is clamped ~0.8V; verified on
    scope: ~750mV pp field-present vs ~300mV pp noise floor). Threshold 550 counts.
    - Actuator (LEDC servo), CT sensor backend, controller state machine
    - Matter module is still a non-functional stub (replaced by the pivot)
    - .gitignore excludes .embuild (5.6G ESP-IDF tr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
    [actuator.rs, config.rs, main.rs]
2026-06-22 Matter Stage 1: Thread+BLE stack builds for ESP32-H2 (vendored esp-idf-matter)
    Pivots from the non-functional rs-matter stub to esp-idf-matter's Thread+BLE
    Matter stack. The firmware now compiles and links for esp32h2; on first boot it
    will commission over BLE and print a scannable QR + pairing code (auto-emitted
    by run_coex), then operate over Thread.
    Build/deps:
    - Cargo.toml: esp-idf-matter (vendored, see below) + static_cell/rand +
    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
    [partitions.csv]
2026-06-22 Matter Stage 2: wire HomeKit On/Off to the actuator reset trigger
    Endpoint 1's On/Off is now backed by node::PlugHooks (impl OnOffHooks) instead
    of rs-matter's stock test logic:
    - HomeKit toggling the endpoint ON fires ToController::ManualTrigger to the
    controller task (which runs one actuator reset cycle; re-triggers during an
    in-progress cycle are ignored, so firing on every ON is safe).
    - The controller reports cycle state back via ToMatter::SetPlugOnOff; PlugHooks::
    run() drains that channel and reflects it into the cluster attribute using
    OutOfBandMessage::Update (re-reads on_off() and reports WITHOUT calling
    set_on_off, so there is no trigger feedback loop). The tile shows O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
    [main.rs]
2026-06-23 Diagnose Bluedroid init failure on H2: free heap + add heap logging
    On real H2 hardware the firmware boots, starts Thread, inits the BLE controller,
    then panics: "Bluedroid Initialize Fail" (ESP_FAIL) at BtDriver::new in the
    vendored esp-idf-matter thread.rs. The BLE controller comes up fine; only the
    Bluedroid *host* fails — the classic low-heap signature (Bluedroid mallocs a
    large env at init; H2 has only ~320 KB SRAM vs the C6's 512 KB the reference
    targets).
    - Shrink rs-matter static allocations (max-subscriptions-1, max-im-buffers-5,
    max-sessions-8) to enlarge the heap. Static .bss drops ~100.8KB -> 89.4KB,
    i.e. ~11 KB more heap for Bluedroid.
    - Add free-heap logging in node.rs (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
2026-06-23 Trim Bluedroid + Matter further for H2 (heap was only 52 KB at BLE init)
    First heap-freeing pass wasn't enough: hardware logged 53,804 bytes free before
    Bluedroid init and it still failed. This pass attacks both sides:
    - Bluedroid footprint: CONFIG_BT_ACL_CONNECTIONS=1 (a Matter device needs only
    one BLE link, for commissioning) shrinks the init env-malloc;
    CONFIG_BT_BTC_TASK_STACK_SIZE 15000 -> 8192 (still 2x the IDF default) cuts the
    heap the BTC task grabs at init.
    - More static RAM freed: max-im-buffers 5 -> 4, max-sessions 8 -> 4. Static .bss
    100.8 KB (orig) -> 86.2 KB.
    - Diagnostic now also logs the LARGEST CONTIGUOUS free block, since a big single
    malloc can fail from fragm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
2026-06-23 Add verbose Bluedroid init logging to diagnose persistent ESP_FAIL on H2
    Heap freeing took us 52 -> 57 -> 71 KB free (67.5 KB largest block, not
    fragmented) and Bluedroid init STILL fails — so it may not be raw heap size.
    Enable BT OSI/BTU/BTC/BTM trace logging at DEBUG so esp_bluedroid_init prints the
    actual failure reason (allocator OOM vs coexistence vs config). Temporary; revert
    once diagnosed.
    Note: NimBLE (the lighter host Espressif uses for H2 Matter) is not a config
    switch here — esp-idf-svc's GATT server is Bluedroid-only, so NimBLE would need
    upstream esp-idf-svc/esp-idf-matter work.
2026-06-23 Free ~7 KB more (matter thread stack + bump arena) for end of BLE init
    New on-device log: Bluedroid now gets all the way through init, Enable, BLE
    Gap+GATTS, into concurrent commissioning mode — then dies at BTA_DmSetDeviceName
    with free=204, largest=136. The heap is scraped to the floor by the end of BLE
    bring-up. (Bluedroid feature trims like GATTC/SMP can't be used: esp-idf-svc
    references those symbols unconditionally, so disabling them breaks the build.)
    Two remaining safe-ish levers:
    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
2026-06-23 Archive the esp-idf+Bluedroid attempt: RAM wall on ESP32-H2
    Documents how far the esp-idf-matter/Bluedroid stack got (boots, Bluedroid +
    BTP fully init) and why it can't be finished on the H2's 320 KB SRAM (Matter
    network task fails to spawn, OutOfMemory; Bluedroid can't be trimmed because
    esp-idf-svc references GATTC/SMP symbols unconditionally). This commit is the
    resume point for the esp-idf approach; the no-std rewrite continues on a new
    branch.
2026-06-23 no-std rewrite Phase 1: esp-hal skeleton builds for ESP32-H2
    After the esp-idf+Bluedroid attempt hit a hard RAM wall, start the bare-metal
    rewrite. New crate rcd-nostd/ targets riscv32imac-unknown-none-elf on nightly.
    Verified version matrix (from esp-rs/openthread esp example) compiles in ~27 s:
    esp-hal 1.1 + esp-rtos 0.3 + esp-radio 0.18 (ieee802154+BLE) + esp-alloc 0.10 +
    embassy. main.rs boots esp-hal/esp-rtos/embassy + heap and logs free heap.
    docs/no-std-plan.md captures the full stack (adds openthread for Thread,
    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
2026-06-23 no-std Phase 2: Thread (OpenThread) stack builds for ESP32-H2
    Add the openthread crate (esp-rs/openthread) + tinyrlibc and bring up a Thread
    node: EspRadio over the H2 IEEE802154 peripheral, OpenThread::new_with_udp_srp,
    join via THREAD_DATASET, info loop logging addrs + free heap.
    Compiles+links for riscv32imac-unknown-none-elf: openthread-sys uses the prebuilt
    OpenThread lib for our target, and mbedtls-rs-sys builds mbedtls on the fly
    (needs cmake + a riscv-capable clang — brew LLVM, NOT Apple clang; documented in
    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
2026-06-23 no-std Phase 2: log Thread device role/ext_pan_id (join signal)
    Add ot.net_status() to the info loop so attaching to a mesh is unmistakable
    in the serial log (role Disabled->Child/Router/Leader, ext_pan_id Some).
2026-06-23 no-std Phase 3: Thread + BLE coexistence builds for ESP32-H2
    Add trouble-host BLE alongside the OpenThread node, both on the shared H2 radio
    (esp-radio with ieee802154 + ble). main runs a trouble peripheral (advertise +
    placeholder GATT service) concurrently with the Thread status loop via embassy
    join. This is the coex Matter needs: commission over BLE, operate over Thread.
    Version matrix (hard-won; see docs/no-std-plan.md):
    - openthread pins esp-radio 0.18 -> bt-hci 0.8.1, so BLE must be trouble-host 0.6
    (also bt-hci 0.8.1); trouble main/0.7 needs bt-hci 0.9 and won't typecheck.
    - trouble 0.6 uses embassy-sync 0.7, so this crate's direct embassy-sync dep is
    pinned to 0.7 (its #[gatt_s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
    [main.rs]
2026-06-23 no-std: robust build wrapper (cmake 3.x) + Phase 3 hardware-validated
    Phase 3 (Thread+BLE coex) confirmed on real H2: advertises as "RCD-Reset",
    accepts a BLE connection, Thread + BLE coexist. Foundation proven on silicon.
    Fix the host build so it's reproducible:
    - build.sh: a wrapper that puts brew-LLVM clang (riscv-capable; Apple clang isn't)
    + the esp-idf-bundled cmake 3.30.2 + LIBCLANG_PATH on PATH, and passes args
    through (./build.sh run --release). cmake 4.x injects `-arch` into the riscv
    mbedtls cross-compile (rejected by clang) even with CMAKE_SYSTEM_NAME=Generic;
    cmake 3.x is required.
    - Document the cmake-version gotcha + the stale-mbedtls-cache recovery in
    docs/no-std-p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
2026-06-23 no-std Phase 4a: full Matter graph builds (rs-matter + Thread + BLE)
    Add rs-matter-stack (alloc + rustcrypto) + rs-matter via [patch.crates-io]
    (sysgrok next). The entire no-std stack now compiles together for ESP32-H2:
    esp-hal + esp-radio + openthread (Thread) + trouble (BLE) + rs-matter (Matter).
    Resolved a hard crypto-version conflict: esp-radio's 802.15.4 ccm 0.4.4 pins
    `subtle = "=2.4"` exactly, vs rs-matter's subtle ^2.6. Fix:
    - vendor/ccm = ccm 0.4.4 with the pin relaxed to ^2.4 ([patch.crates-io] ccm),
    - direct `subtle = "2.6"` dep forcing unification to 2.6.1 (API-compatible for
    ccm's constant-time tag compare). ccm 0.4.4 (esp-radio) + ccm 0.5 (rs-matter)
    now coexist on one sub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
2026-06-23 no-std Phase 4b (6/6): wire run_matter — full Matter stack compiles
    src/matter/stack.rs run_matter(): builds a ThreadMatterStack and runs it via
    run_coex(PreexistingWireless::new(<the 5 adapters>), &crypto, (NODE, handler),
    kv, ()). Uses rs-matter TEST device credentials + DummyKvBlobStore (no-persist) —
    enough to commission for bring-up; real DAC + flash KV come later. Placeholder
    On/Off light on EP1 (Phase 5 swaps in the RCD plug). EspRng shims a rand_core 0.6
    CryptoRngCore over esp-hal's Rng for the crypto provider.
    Two rev gotchas fixed: the build compiles rs-matter 0.2.0 (843b410) /
    rs-matter-stack 054505c, not the esp-idf revs I'd referenced — the 0.2.0 KV API
    is `stack.matter()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
    [stack.rs]
2026-06-23 no-std Phase 4b complete: main runs the Matter stack
    Switch main() from the Phase-3 Thread+BLE demo to matter::run_matter(ot,
    controller, eui64, rng). Thread is no longer brought up manually — the
    commissioner supplies the operational dataset over BLE and OtNetCtl applies it.
    Removed the demo's placeholder GATT server + thread_status_loop + the standalone
    ble_peripheral/advertise/gatt_events (superseded by the BTP service in
    matter/gatt.rs) and the THREAD_DATASET const.
    The complete no-std Matter-over-Thread firmware compiles end-to-end with zero
    warnings: esp-hal + esp-radio + openthread (Thread) + trouble (BLE) + rs-matter,
    all five PreexistingWireless adapters + the run wiring. Commiss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
    [main.rs]
2026-06-24 no-std: fix NoNetworkInterface at startup + adapter diagnostics
    Symptom: `Matter stack exited: NoNetworkInterface` immediately after starting the
    stack (uncommissioned).
    Likely cause: main brought up no network interface at all (Thread bring-up was
    removed entirely), so the operational side has no netif to initialize against
    during BLE commissioning. Fix: `ot.enable_ipv6(true)` at startup — brings the
    IPv6 interface up (link-local) WITHOUT attaching Thread; the commissioner still
    supplies the dataset over BLE (OtNetCtl applies it).
    Also: make OtMdns srp_autostart non-fatal (it must wait for Thread, not error),
    and add entry/error logging to OtGattPeripheral + OtMdns so the exact failing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
    [main.rs]
2026-06-27 no-std: BLE commissioning fixes + EMF power-monitor / actuator control
    Commissioning (src/matter/):
    - enable rs-matter-stack `log` feature so the commissioning QR + PairingCode
    actually print (rs-matter's internal logging is gated on it)
    - fix BLE static-random address: set the top two bits on byte 5 (BdAddr is
    little-endian), not byte 0 — bad address was rejected with HCI 0x12
    - read ATT MTU fresh on each BTP op instead of caching 23 at connect (trouble
    raises it to 247 after the peer's ExchangeMTU); stale 23 stalled commissioning
    - gatt to_err maps to BtpError, not NoNetworkInterface; advertise/connect logs
    - TestOnOffDeviceLogic::new(false) to silence the 5s placeholder toggle spa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
    [actuator.rs, config.rs, main.rs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]
2026-06-27 no-std: fix LEDC PWM frequency on ESP32-H2 (actuator stuck extended)
    Hardware bisect (old esp-idf code retracts the actuator, new code pins it
    fully extended) showed esp-hal was generating the wrong PWM frequency, not a
    duty problem: at ~1/3 of 50 Hz both 5% and 10% duty produce pulses >=2 ms, so
    the actuator saturates fully extended regardless of the commanded position.
    On the H2, Ledc::set_global_slow_clock(APBClk) selects ledc_sclk_sel=0, which is
    actually the 32 MHz XTAL (the H2 LEDC has no APB source), but esp-hal computes
    the timer divisor from Clocks::get().apb_clock (96 MHz on the default preset).
    Achieved frequency = requested * 32MHz / apb_clock.
    Compensate by pre-scaling the req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
    [actuator.rs]
2026-06-27 no-std: debounce power loss + exponential retry backoff
    Rework the controller's reset timing:
    - require 60s of continuous power loss before the first actuator activation
    (debounces brief dropouts/sensor glitches; power returning cancels the reset)
    - after the first cycle, retry with exponential backoff: 2 min, then doubling,
    capped at 24 h, until power returns
    - power restoration during the debounce or any backoff wait aborts back to idle
    monitoring; each new outage starts the sequence fresh
    Replaces the old fixed single-retry logic. New config constants:
    POWER_LOSS_DEBOUNCE_MS, INITIAL_RETRY_DELAY_MS, RETRY_BACKOFF_FACTOR,
    MAX_RETRY_DELAY_MS (removed MAX_AUTO_RETRIES, POST_ATTEMPT_WA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
    [config.rs]
2026-06-28 no-std: rework EMF sensor for LM358 remote front end + calibrated ADC
    The power sensor was redesigned around an LM358 op-amp (amplify + buffer at
    the antenna, drive a multi-foot shielded cable to the ESP). Adapt the firmware
    to it and fix detection:
    - Use calibrated ADC reads (AdcCalLine) on GPIO4/ADC1_CH3. The H2's raw ADC
    has a large offset/gain error (read ~3730 for 1.65 V), jamming the operating
    point against the 4095 ceiling and clipping the swing. Calibrated reads return
    millivolts with the bias mid-range and full headroom.
    - Detection threshold is now peak-to-peak millivolts (95 mV), field-calibrated
    with the 2.2 nF feedback low-pass on the amp.
    - Richer debug logging (pp/min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
    [config.rs, sensor.rs]
2026-06-28 no-std: replace retry backoff with two-cycle latch state machine
    Rework the auto-reset flow per the intended behaviour:
    1. On power loss, debounce 60 s of continuous absence.
    2. Run one actuator cycle.
    3. Watch a further 60 s of continuous absence; if power returns the cycle
    worked → back to monitoring.
    4. Still absent → run a second (final) actuator cycle, then LATCH.
    5. Latched: stop actuating; re-arm only after power is continuously present
    for 10 s.
    Removes the exponential-backoff retry loop (INITIAL_RETRY_DELAY_MS,
    RETRY_BACKOFF_FACTOR, MAX_RETRY_DELAY_MS) in favour of POST_RESET_RECHECK_MS
    and POWER_RESTORE_CONFIRM_MS, and adds wait_for_sustained_power() to co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
    [config.rs]
2026-07-03 Remote EMF sensor design and production files
    [BOM_Board1_PCB1_2026-07-02.xlsx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]
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2026-07-06 no-std: full RCD Matter-over-Thread device — persistence, real device model, H2 radio fixes
    End-to-end working on hardware: commissions over BLE in Apple Home, operates over
    Thread, drives the actuator and reports mains presence bidirectionally, and survives
    reboots. This squashes the branch's uncommitted working state into one checkpoint.
    Device model (src/matter/):
    - EP1 On/Off Plug-In Unit (0x010A) — momentary; On fires one actuator reset cycle
    (plug.rs, RcdPlugHooks: OnOffHooks), auto-returns to Off.
    - EP2 Contact Sensor (0x0015) + Boolean State — mains presence, HomeKit trip alert
    (contact.rs; hand-written handler, rs-matter ships none).
    - link.rs bridges the autonomous contr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
    [main.rs, stack.rs]
2026-07-12 no-std: supervise the Matter stack — restart on unforeseen exit instead of dying
    Previously `run_matter` called `stack.run(...)` once; if it ever returned an error the
    Matter stack was dead until the next reboot (main only logged it). Wrap it in a
    supervised loop that restarts the stack on any exit (Ok or Err), with a 2 s pause so a
    hard-failing restart can't spin the CPU. A border-router outage does NOT trigger this
    (its report/reconnect failures are handled internally); this guards genuinely unforeseen
    internal/transport errors. The controller's safety loop runs in a separate task and is
    unaffected, and Thread/SRP stay up across a restart (OpenThread runs in its own task), so
    recovery is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
    [main.rs, stack.rs]
2026-07-12 no-std: fix StaticCell double-init panic in the Matter restart loop
    The supervised run loop rebuilt the KV each iteration via FlashKv::new(), which claims a
    module StaticCell buffer and panics on the second call ("StaticCell is already full") —
    hit immediately on hardware because startup + the first loop iteration already call it
    twice. Build the FlashKv once outside the loop (as before) and share it with every run by
    reference: rs-matter's `kv()` returns an owning `impl KvBlobStoreAccess`, and `&T` also
    impls KvBlobStoreAccess, so `&kv` satisfies `run()`'s bound without reconstructing the
    store. The other per-iteration constructors (BLE controller, adapters, handler chain) are
    free of one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
    [stack.rs]
2026-07-12 no-std: don't re-init BLE on operational stack restarts (fixes task-stack leak/OOM)
    An error-injection test of the supervised restart loop showed it recovers correctly but
    leaks: each BleConnector::new() spins up a heap-allocated BLE controller RTOS task, and
    dropping the connector on restart doesn't reclaim that stack — after enough restarts the
    heap is exhausted (panic in esp_rtos task_create). An operational restart doesn't need
    BLE at all: once commissioned the non-concurrent stack never calls Gatt::run. So build a
    real controller only while un-commissioned; otherwise use the new
    OtGattPeripheral::without_controller (controller = None), which initializes no BLE stack.
    Since run() only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
    [stack.rs]
2026-07-12 no-std: make the contact sensor the primary Home tile (swap endpoint order)
    Apple Home treats the first application endpoint (lowest endpoint ID, listed first in
    the node's PartsList) as the primary accessory tile. Power state is the at-a-glance
    info that matters, so make the contact sensor endpoint 1 (primary) and move the On/Off
    plug to endpoint 2 (secondary) — they were the other way round. Only the endpoint IDs
    and NODE ordering change; the handler chain and per-endpoint logic reference the
    constants, so they follow automatically.
    Takes effect on a fresh commissioning (device composition change → re-pair after flash);
    Apple's exact primary-selection heuristic isn't publicly specifie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
    [stack.rs]
2026-07-12 Reorganize repo: promote no-std firmware to root, drop esp-idf attempt
    The no-std (esp-hal) Matter-over-Thread firmware is the shipping solution, so make it
    the repository root and remove the abandoned esp-idf+Bluedroid attempt.
    - Move rcd-nostd/* to the repo root (src, vendor, Cargo.*, build.rs/sh, .cargo,
    rust-toolchain.toml) — history preserved via renames. The crate keeps its name.
    - Delete rcd-reset-controller/ entirely (the esp-idf attempt; archived at git tag
    esp-idf-attempt-final / branch vibe-code-1). Its bundled cmake 3.30.2 — which the
    build needs (system cmake 4.x breaks the riscv mbedtls build) — is preserved under
    ./tools/cmake/ (gitignored); build.sh now resolve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
    [partitions.csv]
2026-07-12 docs/comments: drop the esp-idf-attempt narrative; document why no-std
    The repo is the shipping no-std firmware, so trim the migration/attempt history and
    keep only the reason it's built this way.
    - docs/no-std-plan.md: reframed from a rewrite "plan" (phases, "reusable from the esp-idf
    version") into an architecture doc. Keeps a short "Why no-std" summary (the ESP-IDF RAM
    wall on the H2's 320 KB SRAM) and the durable implementation detail: stack table,
    transport layer, non-concurrent commissioning, vendored esp-radio, flash persistence,
    the BLE version matrix, and the ccm/subtle crypto conflict.
    - docs/phase4b-glue-design.md: dropped the "Template: esp-idf-matter ..." references and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
    [config.rs]
2026-07-12 Add project README
    High-level, non-technical introduction: what the device does (battery-powered mains
    detection + automatic breaker/RCD reset via a linear actuator, controlled and monitored
    from Apple Home over Matter/Thread), the hardware (ESP32-H2 + custom EMF sensor board +
    Actuonix L12 actuator), the no_std Rust / Matter-over-Thread stack, how to build, and
    links to the detailed docs.
2026-07-13 De-vendor esp-radio and ccm; consume the H2/subtle fixes from yvf forks
    Remove the vendored esp-radio (0.18.0 + ESP32-H2 802.15.4 RX fixes) and ccm
    (0.4.4 + relaxed subtle pin) source trees and consume both from branches on
    the public yvf forks via [patch.crates-io]:
    esp-radio -> github.com/yvf/esp-hal @ rcd/esp-radio-0.18-h2-154-fixes (4b0e8323)
    (published 0.18.0 crate + the ext-addr + receive-path fixes)
    ccm -> github.com/yvf/AEADs @ ccm-0.4.4-relax-subtle (790a0a5)
    (ccm 0.4.4 with subtle "=2.4" relaxed to "2", so it unifies at 2.6)
    No public ccm 0.4.x relaxes the subtle pin and esp-radio 1.0.0-beta.0 needs an
    API migration, so both fixes ride on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
2026-07-13 Replace multibyte Unicode punctuation with ASCII across source and docs
    Mechanical de-unicoding of typographic characters in comments, prose, and
    log-message strings (log output is cosmetic-only, no logic change):
    em/en dash, minus sign -> - arrows -> -> <-> <-
    ellipsis -> ... ~= -> ~ >=/<= -> >= <=
    multiply sign -> x micro -> u 1/2 -> 1/2
    section-divider box rule -> ---
    Deliberately kept (no clean single-byte equivalent): the box-drawing circuit
    diagrams, ohm sign, and decorative emoji in the emf_sensor/ hardware docs.
    No functional change; project still builds (./build.sh, exit 0).
    [actuator.rs, config.rs, main.rs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]
2026-07-14 Migrate Matter/Thread stack to edge-nal 0.7; use edge-nal-openthread instead of hand-rolled UDP glue; drop the ext-addr esp-radio patch (fixed upstream in openthread #84)
    The ext-address filter byte-order symptom was an esp-rs/openthread bug (its
    platform shim decoded the little-endian ext address with from_be_bytes), not an
    esp-radio bug. It was fixed upstream in openthread PR #84 ("decode little-endian"),
    which makes stock esp-radio's to_le_bytes (esp-hal #5314) correct. So the
    compensating to_be_bytes esp-radio patch is dropped; carrying it on top of a fixed
    openthread would re-reverse the filter.
    openthread 0.2 also removed its own edge-nal integration (enal.rs, PR #83) and
    re-homed it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
2026-07-16 Rebuild firmware on rs-matter-embassy + ivmarkov's 10e48dd esp base; drop the esp-radio fork (stock)
    Adopt rs-matter-embassy (EmbassyThreadMatterStack + EspThreadDriver) as the
    Matter-over-Thread integration, replacing all the hand-rolled transport glue, and
    move to ivmarkov's blessed coordinated stack so our setup is legible to upstream:
    - All esp crates from esp-hal git rev 10e48dd (esp-radio 0.18 WITH #5650, the FCF
    offset fix) via [patch]; openthread/openthread-sys/mbedtls-rs-sys track esp-rs main;
    rs-matter-stack 0.1 / rs-matter 0.2 / edge-nal-openthread 0.1 from crates.io.
    - Drop the yvf esp-radio fork entirely -> STOCK esp-radio (no RX-fix patches). This is
    the correct #5650 ba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
    [actuator.rs, main.rs, stack.rs]
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2026-07-18 actuator: fix clock freq issue causing all pulses to come out as extend
    [actuator.rs]
